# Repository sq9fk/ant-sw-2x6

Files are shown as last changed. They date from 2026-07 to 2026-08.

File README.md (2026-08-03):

# SP9PDF RemoteQTH Antenna Switch (6×2)

Firmware sterownika przełącznika antenowego **6 anten × 2 TRX** oparty na projekcie
[RemoteQTH 6×2 Antenna Controller](https://remoteqth.com/6x2-antenna-controler.php)
(oryginał **OK1HRA**, rev 0.3), zmodyfikowany przez **SQ9FK** na potrzeby stacji **SP9PDF**.

Urządzenie pozwala dwóm transceiverom niezależnie i bezkolizyjnie korzystać ze wspólnego
zestawu anten, z ochroną przed konfliktem, gdy oba TRX żądają tej samej anteny. Sterowanie
odbywa się ręcznie (enkoder/LCD + interfejs WWW); automatyka BCD z radia oraz blokowanie
przez PTT to funkcje **opcjonalne** (patrz [Funkcje opcjonalne](#funkcje-opcjonalne-sq9fk)),
domyślnie wyłączone.

Rozwój firmware (modyfikacje SQ9FK, dokumentacja, symulator WWW) prowadzony jest przy wsparciu
[Claude Code](https://claude.com/claude-code) (Anthropic).

## Sprzęt

- Platforma: **Arduino Nano** (ATmega328P)
- Ekspandery I/O: **MCP23017** na magistrali I²C (adresy 0x20–0x23)
- Wyświetlacz: **LCD 16×2** (jedna linia na TRX)
- Wejścia: enkoder obrotowy + podświetlany przycisk (menu ręczne)
- Pomiar napięcia zasilania na `A3` (ostrzeżenia LOW/HIGH < 10 V / > 15 V)
- Moduł Ethernet **W5500** (interfejs WWW) — w firmware **domyślnie włączony** (`#define EthModule`)

Dokumentacja sprzętowa w repo:
- Schemat (SVG): [`docs/6x2-antenna-switch-control-03-sch.svg`](docs/6x2-antenna-switch-control-03-sch.svg)
- Projekt **KiCad** rev 03 (schemat + PCB + netlista): [`hw/`](hw/)
- **Analiza połączeń** (pinout MCU, I²C, przekaźniki, BCD/PTT, OTRSP), zweryfikowana
  netlistą: [`docs/CONNECTIONS.md`](docs/CONNECTIONS.md)
- **Architektura firmware** (model stanu, pętla, serwer WWW, flagi funkcji):
  [`docs/DESIGN.md`](docs/DESIGN.md)

Źródło sprzętu: RemoteQTH / OK1HRA, licencja **CC BY-SA 4.0**
(<https://remoteqth.com/6x2-antenna-controler.php>).

## Funkcje / modyfikacje SQ9FK

W stosunku do oryginału OK1HRA (rev 0.3) wprowadzono:

- **6 anten (projekt pierwotny)** — czysty one-hot `bit0..bit5` = anteny 1..6 (bez dawnej
  7. pozycji i bez sprzężenia GXP11 4/5).
- **Radio Flex — dwa niezależne wyjścia** na `GPA7`/`GPB7` (przekaźniki `K1`/`K2`, złącza
  `J7`/`J6`), przełączane **ikonami power w wierszach TRX** (WWW), niezależne od wyboru anteny.
  Dawniej `bit7` = przekaźnik pasma GXP11 40 m.
- **Nowy wygląd WWW** wg konwencji projektu
  [`rotator_wifi_bridge`](https://github.com/sq9fk/rotator_wifi_bridge) — ciemny motyw teal, karty,
  statusy sekcji przy nagłówku „Anteny", legenda „Opis anten", zwijana karta **Settings**.
  **Responsywny (mobile-first)** — cele dotykowe min. 44×44 px poniżej 520 px, wyśrodkowana ikona
  Flex, siatka przycisków TRX zawsze wyrównana do lewej krawędzi karty niezależnie od liczby
  zawiniętych linii (etykieta TRX na własnym pełnym wierszu na wąskich ekranach). **Siatka anten
  na mobile (2026-08-02)** — wiersz zawija się deterministycznie na **4+4** (`-,1,2,3` / `4,5,6,
  power`), oba wiersze wypełniają całą szerokość karty równymi przyciskami (`flex:1 1 0`); ikona
  power już nie „ucieka" auto-marginesem na prawy kraniec, gdy zostanie sama w krótkim,
  zawiniętym wierszu (na desktopie bez zmian — nadal przy prawej krawędzi w jednym wierszu).
- **Edycja nazw przez WWW** (`WWW_EEPROM_NAMES`, karta Settings) — **nazwa stacji** (topbar) oraz
  nazwy anten 1–6, zapisywane w EEPROM (trwałe), z limitem długości 11 znaków.
- **Konfiguracja sieciowa edytowalna przez WWW** (karta Settings) — **IP, brama, maska, DNS**
  zamiast na sztywno w kodzie; zapisywane w EEPROM (`IPAddress::fromString`, walidacja — błędny
  adres jest ignorowany, stara wartość zostaje). Zmiana wymaga restartu urządzenia.
- **Awaryjna edycja sieci przez Serial (2026-08-02)** — gdy urządzenie ma źle skonfigurowane IP
  (lub bramę/maskę) i strona WWW jest nieosiągalna, IP/gateway/maska/DNS da się poprawić bez
  sieci: podłącz USB, otwórz terminal szeregowy (9600 8N1, zakończenie linii CR — w Arduino
  Serial Monitor „Both NL & CR" albo „Carriage return") i wyślij `NI=192.168.2.150`
  (analogicznie `NG=`/`NM=`/`ND=` dla bramy/maski/DNS — dokładnie ten sam format co WWW
  `/?N{I|G|M|D}={a.b.c.d}`, tylko bez `/?`). Urządzenie odpowiada `OK` albo `ERR` (błędny adres —
  stara wartość zostaje). Dostępne we wszystkich wariantach ze skonfigurowaną siecią
  (`EthModule` i/lub `OTRSP_TCP`), niezależnie od tego, czy `OTRSP` (USB) jest włączony — jeśli
  jest, komenda `N{kod}=` jest rozpoznawana przed przekazaniem reszty do parsera OTRSP, więc oba
  mechanizmy współdzielą ten sam port bez kolizji.
- **Odczyt stanu dla `rotator_wifi_bridge`** (`GET /?J` → `A=<trx1>,<trx2>`, `GET /?K` →
  `K=<nazwa1>,…,<nazwa6>,<nazwa stacji>`) — pozwala mostowi
  [`rotator_wifi_bridge`](https://github.com/sq9fk/rotator_wifi_bridge) (panel WWW rotora anteny)
  pokazać stan, **prawdziwe nazwy anten**, **nazwę samego przełącznika** i przełączać TRX1/TRX2
  z jednego miejsca, zwykłym HTTP GET (`/?S{bank}{kod}`, tak jak własny panel WWW tego urządzenia)
  — bez OTRSP, które zostaje zarezerwowane wyłącznie dla programu logującego. Oba endpointy
  reużywają istniejący nagłówek HTTP (`HTTP_HEAD`) zamiast nowego literału, koszt: **+68 B** (`/?J`),
  **+72 B** (`/?K`, 6 nazw anten) i dodatkowe **+16 B** za 7. pole (nazwa stacji) zamiast osobnego
  endpointu (patrz `docs/DESIGN.md` §7/§9) — **zapas na domyślnym wariancie to już tylko ~90 B**.
- **Sterowanie OTRSP** (SO2R, zgodne z [protokołem OTRSP](https://www.k1xm.org/OTRSP/OTRSP_Protocol.pdf))
  — komendy `AUX1`/`AUX2`, zapytania `?AUX1`/`?AUX2`/`?NAME`/`?`, zgodne m.in. z N1MM+. Komendy
  kończy CR (`\r`), zgodnie ze specyfikacją. Kanał USB (`OTRSP`, domyślnie **wyłączony**) i surowe
  gniazdo TCP (`OTRSP_TCP`, domyślny port 4534, domyślnie **włączone**) są **niezależne** — można
  włączyć jeden, drugi, albo oba naraz; sam parser komend jest wspólny
  (`OTRSP_parse(cmd, Print&)`), każdy kanał ma własny, niezależny bufor linii. Każdy z nich, oraz
  **oba naraz**, mieszczą się razem ze stroną WWW (`EthModule`) — `OTRSP` (USB) z zapasem ~1,1 KB,
  `OTRSP_TCP` (gniazdo TCP, **domyślny build**) z zapasem ~398 B, oba naraz z zapasem ~346 B
  (patrz uwaga niżej) — żadna kombinacja nie jest już blokowana.
- **Automatyka BCD i blokowanie przez PTT** — dostępne jako opcje (`BCD_INPUT`, `PTT_BLOCKING`),
  domyślnie wyłączone (patrz [Funkcje opcjonalne](#funkcje-opcjonalne-sq9fk)).
- **Watchdog** (`<avr/wdt.h>`, zawsze włączony) — jeśli `loop()` się zawiesi (na WWW, TCP OTRSP,
  USB OTRSP albo czymkolwiek innym) i nie wróci w ciągu ~8 s, urządzenie samo się resetuje.
  Włączany dopiero na końcu `setup()` (po wszystkich `delay()` przy starcie — LCD/IP splash), żeby
  nie zresetować urządzenia w trakcie rozruchu.
- **Przycisk „Restart" w Settings** — realny, programowy restart urządzenia z poziomu WWW (nie
  tylko informacja, że trzeba go ręcznie zrestartować). Wykorzystuje watchdog ze skróconym
  timeoutem (15 ms) — jedyny niezawodny sposób softwarowego resetu na AVR (czyści też peryferia,
  nie tylko licznik rozkazów, w przeciwieństwie do skoku na adres 0).
- **Ostrzeżenia napięciowe** — czerwona kropka statusu w topbarze przy napięciu poza 10–15 V oraz
  ostrzeżenie na LCD — **nieblokujące** (nie zamrażają WWW/przełączania podczas awarii). Samo
  napięcie nie jest już pokazywane liczbowo w Settings (usunięte dla oszczędności flash).
- **Zawsze static IP** — bez DHCP (usunięte z projektu, patrz niżej) — urządzenie startuje pod
  stałym adresem, ustawionym w `src/main.ino` lub edytowalnym po flashowaniu przez WWW+EEPROM
  (patrz „Konfiguracja sieciowa" wyżej), IP na LCD widoczne od razu przy starcie.
- Optymalizacja rozmiaru firmware (PROGMEM, pętle WWW) i utwardzenie serwera WWW.
- **Przegląd bezpieczeństwa/poprawności (2026-07-29)** — 6 poprawek: (1) walidacja zakresu w
  OTRSP `AUX1n`/`AUX2n` (wartości >6 wcześniej powodowały odczyt poza tablicą `antRAM[]` przy
  najbliższym odświeżeniu LCD/WWW); (2) timeout 2 s na odczyt żądania WWW (wolny/zawieszony
  klient trzymał `loop()` w nieskończonej pętli, docelowo do resetu przez watchdog); (3) `volatile`
  dla zmiennych dzielonych z ISR enkodera (`enc0Pos`, `e`, `Timeout[]`); (4) usunięcie `String` z
  `show()` (heap-alokacje co ~100 ms — przy okazji odzyskało **~660 B flash**, znacznie
  poprawiając zapas domyślnego buildu); (5) `enc2()` używa własnego parametru zamiast globalnej
  zmiennej; (6) powiększony bufor żądania WWW (56 B zamiast 48 B — mocno zakodowana 11-znakowa
  nazwa anteny mogła się wcześniej obcinać w połowie).
- **Odblokowany 6. wariant (2026-08-01)** — strona WWW + OTRSP po USB **i** po TCP jednocześnie
  (`EthModule`+`OTRSP`+`OTRSP_TCP`) była dotąd blokowana przez `#error` (brakowało ~116 B); po
  odzyskaniu flash w przeglądzie z 2026-07-29 kombinacja faktycznie się mieści (zmierzone wtedy:
  97,3%/29896 B) — `#error` usunięty, wszystkie sześć wariantów jest teraz dostępnych.
- **Nazwa stacji na LCD wyśrodkowana (2026-08-02)** — była drukowana zawsze od kolumny 0 (z boku
  dla krótszych nazw); teraz liczona jest jej długość (`siteNameLen()`) i wyliczana kolumna
  startowa dla wyśrodkowania na 16-znakowej linii.
- **Strona WWW nie zwija już Settings w trakcie edycji (2026-08-02)** — dawny
  `<meta http-equiv="refresh">` przeładowywał stronę bezwarunkowo co 10 s, więc rozwinięta karta
  Settings (`<details>`, stan tylko w DOM, nie zapisany po stronie urządzenia) zwijała się z
  powrotem, zanim dało się zapisać zmianę. Zastąpione małym inline `<script>`: strona nadal
  odświeża się co 10 s, ale **tylko gdy żaden `<details>` nie jest rozwinięty** — w przeciwnym
  razie sprawdzenie jest odraczane co 2 s, aż użytkownik zwinie Settings.
- **Biblioteka Ethernet: oficjalna `arduino-libraries/Ethernet`** (była `adafruit/Ethernet2` —
  przestarzała/nieutrzymywana). Kosztuje więcej flash niż Ethernet2 (obsługa W5100/W5200/W5500
  z auto-detekcją chipu w runtime, niewyłączalna `#define`m). **DHCP usunięte z projektu** —
  kosztowało ~3,8 KB flash, a przydatne było tylko w wariantach bez strony WWW; nie warto było
  trzymać całej ścieżki kodu dla tego jednego przypadku. Strona WWW działa zawsze na
  **static IP** (ustaw `ip`/`gateway`/`subnet` w `src/main.ino` pod docelową sieć).

Domyślne nazwy anten są w `antDefault[]`, domyślna nazwa stacji w `siteDefault` (`src/main.ino`).
Przy włączonym `WWW_EEPROM_NAMES` nazwa stacji i nazwy anten 1–6 są **edytowalne przez WWW** (karta
Settings) i zapisywane w EEPROM (patrz niżej).

## Konfiguracja (dyrektywy `#define`)

| Define | Domyślnie | Opis |
|---|---|---|
| `Inputs` | 6 | liczba anten (stała — zmiana nie jest w pełni zaimplementowana) |
| `Ports` | 2 | liczba par IN/OUT i linii LCD (wspiera 2–4) |
| `inputHigh` | **WŁ.** | poziom aktywny wejść (HIGH) |
| `OTRSP` | WYŁ. | włącza sterowanie OTRSP po porcie szeregowym |
| `OTRSP_TCP` | **WŁ.** | surowy TCP dla OTRSP — niezależne od `OTRSP`; domyślnie razem z `EthModule` (zapas ~398 B) |
| `OTRSP_TCP_PORT`| 4534 | port surowego TCP dla OTRSP |
| `SERBAUD` | 9600 | prędkość portu szeregowego |
| `EthModule` | **WŁ.** | włącza moduł Ethernet + interfejs WWW (zawsze static IP, bez DHCP) |

### Funkcje opcjonalne (SQ9FK)

| Define | Domyślnie | Opis |
|---|---|---|
| `WWW_EEPROM_NAMES` | **WŁ.** | edycja nazwy stacji i nazw anten 1–6 przez WWW (karta Settings), zapis w EEPROM, limit `ANT_MAXLEN` (11 zn.) |
| `BCD_INPUT` | WYŁ. | automatyczny wybór anteny z BCD radia (wejścia MCP IN); wyłączony = tryb wyłącznie ręczny (WWW/enkoder), bez przełącznika Manual/BCD |
| `PTT_BLOCKING`  | WYŁ. | odczyt PTT + blokada przełączania podczas TX + plakietka PTT; wyłączony zgodnie ze zmianą HW (gniazda PTT jako wyjścia) |

> **Wykrywanie kolizji** między TRX (blokada tej samej anteny, ≠ OFF) działa **niezależnie**
> od `PTT_BLOCKING` — pozostaje aktywne. Blokada pary 4↔5 (GXP11) z projektu OK1HRA została
> usunięta — poz. 4 i 5 to teraz w pełni niezależne anteny.
>
> **Atrybucja kolizji (2026-08-03)** — gdy dwa TRX zażądają tej samej anteny, na czerwono
> podświetla się **tylko ten TRX, który przełączył się jako drugi** (ten pierwszy, już
> ustabilizowany, zostaje bez zmian) — niezależnie od numeru TRX. Górny chip statusu (mały
> kwadrat z numerem TRX) pokazuje wtedy **„OFF"** zamiast nazwy żądanej anteny, bo dokładnie tak
> wygląda stan przekaźników (wyjście zostaje wymuszone na OFF). Żądanie zablokowanego TRX
> **nie ginie** — jeśli TRX, który zajmuje antenę, ją zwolni (przełączy się gdzie indziej albo na
> OFF), zablokowany TRX automatycznie ją przejmuje **od razu, bez ponownego klikania i bez
> odświeżania strony** (poprawka z 2026-08-04 — poprzednio przejęcie działało tylko wtedy, gdy
> zwalniający TRX miał niższy numer niż zablokowany; w drugą stronę zablokowany TRX zostawał
> zawieszony na OFF aż do ręcznego odświeżenia, mimo że antena była już fizycznie wolna).
> Naprawiono też sytuację, w której strona WWW pokazywała kolor kolizji **sprzed** dopiero co
> wykonanej zmiany (trzeba było ręcznie odświeżyć) oraz fałszywe kolizje przy **OFF+OFF**
> (dwa TRX ustawione na OFF nigdy nie kolidują).

## Struktura repozytorium

```
.
├── platformio.ini                 # konfiguracja budowania (Nano / ATmega328P)
├── src/
│   └── main.ino                   # AKTUALNY firmware SP9PDF/SQ9FK
├── reference/                     # firmware referencyjny (nie budowany)
│   ├── ant-sw-6x2-03_orig.ino     #   oryginał OK1HRA rev 0.3
│   ├── ant-sw-6x2-03.ino          #   wariant rev 03
│   └── ant-sw-6x2-04.ino          #   wariant rev 04
├── docs/
│   ├── 6x2-antenna-switch-control-03-sch.svg   # schemat (RemoteQTH rev 03)
│   ├── CONNECTIONS.md             # analiza połączeń (kod + netlista)
│   └── DESIGN.md                  # architektura firmware (model stanu, WWW, flagi)
├── hw/                            # projekt KiCad rev 03 (OK1HRA, CC BY-SA 4.0)
│   ├── 6x2-antenna-switch-control-03.zip
│   └── 6x2-antenna-switch-control-03/   # .sch, .kicad_pcb, .net, .lib, .pro
├── tools/
│   ├── websim.html                # symulator interfejsu WWW (test wyglądu bez sprzętu)
│   └── serve.py                   # launcher: wystawia symulator i otwiera przeglądarkę
├── README.md
├── CLAUDE.md                      # wskazówki dla Claude Code
└── LICENSE                        # GPLv3
```

## Kompilacja i wgranie

### PlatformIO (zalecane)

```bash
# Nano ze STARYM bootloaderem (57600):
pio run -e nanoatmega328 -t upload
# Nano z NOWYM bootloaderem (115200):
pio run -e nanoatmega328new -t upload
# Podgląd portu szeregowego (9600):
pio device monitor -b 9600
```

`Wire`/`SPI` są w rdzeniu AVR; `LiquidCrystal` i `Ethernet` PlatformIO pobiera automatycznie
z `lib_deps` w [`platformio.ini`](platformio.ini). Ethernet (`#define EthModule`/`OTRSP_TCP`
w `src/main.ino`) to oficjalna biblioteka Arduino `arduino-libraries/Ethernet` (2026-07-29:
zastąpiła przestarzałą `adafruit/Ethernet2`).

> **Domyślna konfiguracja: Ethernet WŁ. + OTRSP po TCP WŁ.** (strona WWW + gniazdo TCP dla
> OTRSP, np. dla N1MM+, port 4534 — static IP). Build zweryfikowany: `pio run -e nanoatmega328`
> → **SUCCESS**, bez ostrzeżeń (Flash **98,7%** / 30322 B — **zapas ~398 B**, RAM **55,0%** / 1127 B
> — domyślne flagi: BCD/PTT wył., nazwy WWW wł., konfiguracja sieciowa edytowalna wł. (WWW **i**
> Serial, patrz „Awaryjna edycja sieci przez Serial" wyżej), watchdog wł., endpointy `/?J`+`/?K`
> dla `rotator_wifi_bridge` wł.). Zapas znacząco się poprawił po usunięciu `String` z `show()`
> (patrz niżej) — wcześniej było ~246 B; od tego czasu zjadły go poprawki UX (siatka mobile,
> atrybucja kolizji — patrz wyżej).
> Wariant **BCD+PTT razem z Ethernetem już się nie mieści** — te opcje bez `EthModule`.
>
> ⚠️ **Oficjalna biblioteka Ethernet kosztuje więcej flash niż Ethernet2** (obsługa
> W5100/W5200/W5500 z auto-detekcją chipu w runtime — niewyłączalna `#define`m, zawsze
> skompilowana). **DHCP usunięte z projektu** — kosztowało ~3,8 KB (`Dhcp.cpp`+`EthernetUdp.cpp`),
> przydatne było tylko w wariantach bez strony WWW; urządzenie zawsze startuje na **static IP**
> (ustaw `ip`/`gateway`/`subnet` w `src/main.ino` pod docelową sieć, albo edytuj po flashowaniu
> przez WWW+EEPROM). Sama strona WWW (HTML/CSS/`BufP`) kosztuje dodatkowo ~8 KB — to ona, nie
> sam Ethernet, zajmuje większość budżetu.
>
> `OTRSP` (USB) i `OTRSP_TCP` (gniazdo TCP) są **niezależne** — każdy może być włączony osobno,
> razem albo osobno, ze stroną WWW (`EthModule`) albo bez niej. Od 2026-07-29 (po przeglądzie
> bugów i odzyskaniu ~660 B flash) **żadna kombinacja już nie jest blokowana** — dawny `#error`
> dla `EthModule`+`OTRSP`+`OTRSP_TCP` naraz (brakowało ~116 B) został usunięty, bo ta kombinacja
> faktycznie się mieści. Sześć wariantów (figury poniżej z 2026-08-03, po poprawkach siatki
> mobile i atrybucji kolizji — patrz wyżej):
> - **Strona WWW + OTRSP po surowym TCP** (**obecnie, domyślne**): `#define EthModule`,
>   `//#define OTRSP`, `#define OTRSP_TCP` → Flash **98,7%** (30322 B), RAM **55,0%** (1127 B)
>   — zapas ~398 B. Wciąż najciaśniejszy z domyślnie używanych wariantów — buduj go najpierw przy
>   każdej zmianie we współdzielonym kodzie (patrz `docs/DESIGN.md` §9/§11).
> - **Strona WWW, static IP, bez OTRSP**: `#define EthModule`, `//#define OTRSP`,
>   `//#define OTRSP_TCP` → Flash **95,7%** (29394 B), RAM **50,8%** (1041 B) — zapas ~1,3 KB,
>   bezpieczniejszy wybór jeśli OTRSP nie jest potrzebne.
> - **Strona WWW + OTRSP po USB**: `#define EthModule`, `#define OTRSP`, `//#define OTRSP_TCP`
>   → Flash **97,1%** (29822 B), RAM **50,8%** (1041 B) — zapas ~898 B
> - **Strona WWW + OTRSP po USB i po TCP jednocześnie**: `#define EthModule`, `#define OTRSP`,
>   `#define OTRSP_TCP` → Flash **98,9%** (30374 B), RAM **55,0%** (1127 B) — zapas ~346 B,
>   **najciaśniejszy ze wszystkich sześciu wariantów** (odblokowany 2026-08-01); jeśli oba kanały
>   OTRSP naraz nie są naprawdę potrzebne, wybierz jeden z dwóch wariantów wyżej — mają wyraźnie
>   więcej zapasu.
> - **OTRSP po USB** (bez strony WWW): `//#define EthModule`, `#define OTRSP`, `//#define OTRSP_TCP`
>   → Flash **33,7%** (10340 B), RAM **36,1%** (739 B) — bez konfiguracji sieciowej (brak
>   `EthModule`/`OTRSP_TCP`), więc bez komend `N{I|G|M|D}=` po Serial.
> - **OTRSP po USB + surowy TCP równolegle** (bez strony WWW): `//#define EthModule`,
>   `#define OTRSP`, `#define OTRSP_TCP` → Flash **69,7%** (21412 B), RAM **54,0%** (1106 B)

### Optymalizacje rozmiaru (zastosowane)

- `port[8][6]`, `BCDmatrixOUT` → `byte` / `PROGMEM`; `ant[]` i glify LCD → `PROGMEM`
  (odczyt: `antName()` / `pgm_read_byte` / `memcpy_P`) — **−264 B RAM**.
- Generowanie przycisków WWW (poz. 0–7) i listy anten zwinięte w pętlę, `switch` na `GET`
  uproszczony do `if` — **−1808 B Flash** (bez zmiany wygenerowanego HTML).

### Optymalizacje serwera WWW (zastosowane)

- **Buforowanie całego wyjścia (`BufP`)** — w bibliotekach Wiznet (Ethernet2 i oficjalna
  `arduino-libraries/Ethernet` — sprawdzone w obu) każde `write()` to osobny segment TCP z
  busy-waitem na `SEND_OK`, a `print(F("..."))` wysyła **znak po znaku** (setki drobnych pakietów).
  Klasa `BufP` zbiera znaki w RAM i oddaje do W5500 porcjami 128 B — cała strona idzie w kilkudziesięciu
  `send()` zamiast tysiąca, **wielokrotnie szybciej** i z krótszą blokadą `loop()`. Statyczny HTML
  (nagłówek/CSS/ikona) też przez ten bufor (`out.print`), na końcu `out.done()`.
- **Batchowany odczyt żądania** — dostępne bajty czytane jednym `client.read(buf,len)` (`recv`)
  zamiast po bajcie, koniec linii wykrywany `memchr` — mniej transakcji SPI na wejściu.
- **Walidacja żądania** (kontrola zakresu banku) — obce żądania (`/favicon.ico`, gołe `GET /`)
  nie przełączają już anten i nie piszą poza tablicą `port[]` (usunięty ukryty błąd OOB).
- Czytanie tylko pierwszej linii żądania (`GET …`) + usunięty debug `Serial.print` —
  krótsza obsługa połączenia. Wygenerowany HTML bez zmian.
- Parsowanie żądania **bez `String`** — bank/kod czytane wprost z bufora `char[16]`
  (usunięty globalny `String HTTP_req`). Brak alokacji sterty na ścieżce żądania.

### Arduino IDE

1. Skopiuj `src/main.ino` do katalogu o tej samej nazwie (`main/main.ino`) lub zmień nazwę.
2. Płytka: *Arduino Nano*, procesor *ATmega328P (Old Bootloader)* w razie potrzeby.
3. Wybierz port COM, *Upload*.

> Uwaga: instalacja biblioteki `Ethernet` (Library Manager, oficjalna Arduino) jest wymagana
> dla `EthModule`/`OTRSP_TCP`. Firmware nie używa DHCP (usunięte z projektu) ani nie wymaga
> żadnych patchy biblioteki — urządzenie startuje zawsze na static IP.

## Symulator interfejsu WWW

Podgląd wyglądu strony urządzenia bez sprzętu — odtwarza HTML/CSS generowany przez firmware.
Symuluje też **protokół OTRSP** (`OTRSP_parse()` z `src/main.ino`) — dwie niezależne, włączane
osobno checkboxami sekcje "OTRSP po USB" / "OTRSP po TCP", każda z monitorem terminala
(wysłane na niebiesko, odebrane na zielono — niezależnie od tego, kto w danym trybie jest
"komputerem", a kto "urządzeniem", patrz niżej) i przyciskami szybkich komend
(`?`, `?AUX1`, `?AUX2`, `?NAME`, `AUX101`, `AUX206`). Komendy `AUX1n`/`AUX2n` faktycznie
przełączają antenę na podglądzie WWW — obie symulacje (WWW i OTRSP) dzielą ten sam stan.

```bash
python tools/serve.py
```

Skrypt wystawia stronę lokalnie (domyślnie `http://127.0.0.1:8765/websim.html`) i otwiera ją
w przeglądarce. Można też otworzyć plik [`tools/websim.html`](tools/websim.html) bez serwera —
ale wtedy **nie działają** poniższe dwie funkcje realnego połączenia (wymagają `http://`).

**Prawdziwe połączenia OTRSP** (nie tylko symulacja w JS):
- **USB** — przycisk „Połącz z prawdziwym urządzeniem" w monitorze USB używa
  [Web Serial API](https://developer.mozilla.org/en-US/docs/Web/API/Web_Serial_API)
  (Chrome/Edge) — przeglądarka prosi o wybór **realnego portu COM** i rozmawia bezpośrednio
  z podłączonym przełącznikiem antenowym (9600 8N1, jak `SERBAUD`). Wysyłane komendy i
  odpowiedzi realnego urządzenia widać w tym samym monitorze co w trybie symulacji.
- **TCP** — przycisk „Uruchom most dla N1MM+" otwiera WebSocket do `python tools/serve.py`,
  który jednocześnie nasłuchuje na **prawdziwym porcie TCP 4534** (jak `OTRSP_TCP_PORT`).
  Prawdziwy N1MM+ (albo inny program OTRSP) może się połączyć z `127.0.0.1:4534` dokładnie
  jak z prawdziwym urządzeniem w wariancie `OTRSP_TCP` — komendy trafiają do przeglądarki przez
  most (surowa "rura" bajtów w Pythonie, `tools/serve.py`), a `OTRSP_parse()` w JS liczy
  odpowiedź i odsyła ją z powrotem tym samym mostem. W tym trybie to **symulator gra rolę
  urządzenia** (odwrotnie niż USB, gdzie to my jesteśmy "komputerem" mówiącym do sprzętu).

## Licencja

- **Firmware** (`src/`, `reference/`): **GPL v3** — patrz [`LICENSE`](LICENSE).
  Oryginał © OK1HRA, modyfikacje © SQ9FK.
- **Sprzęt** (`hw/`, schemat): **CC BY-SA 4.0** © OK1HRA / RemoteQTH.com.

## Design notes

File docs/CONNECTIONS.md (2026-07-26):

# Analiza połączeń — SP9PDF RemoteQTH 6×2 Antenna Switch

> **Dwa niezależne źródła, w pełni zgodne:**
> 1. Firmware [`src/main.ino`](../src/main.ino) — pinout MCU i logika I²C.
> 2. Projekt KiCad rev 03 ([`hw/`](../hw/), © OK1HRA, CC BY-SA 4.0) — netlista
>    `ant-sw-control.net` (128 komponentów, 149 sieci), z której wyprowadzono stronę
>    sprzętową. Pozycje oznaczone **✓ netlista** są potwierdzone bezpośrednio połączeniami PCB.

Płyta rev 03 to wersja **2-portowa (6 anten × 2 TRX)**: 1× Arduino Nano, 2× MCP23017,
2× ULN/UDN (drivery), opcjonalny W5500 (Ethernet), LM2576 (zasilanie).

> **⚠️ Sprzęt vs firmware.** Ten dokument opisuje **możliwości sprzętu** (płyta OK1HRA rev 03).
> Domyślna konfiguracja firmware SQ9FK **nie używa** części z nich:
> - **Ethernet WŁ.** (interfejs WWW), **OTRSP WYŁ.** (wyklucza się rozmiarowo z Ethernetem);
> - wejścia **BCD** (`BCD_INPUT`) i **odczyt/blokada PTT** (`PTT_BLOCKING`) — **wyłączone**;
> - na tej stacji gniazda **PTT przerobiono sprzętowo na wyjścia** (nie służą jako wejścia PTT).
>
> Sekcje 4 (BCD/PTT) i 6 (OTRSP) opisują więc funkcje **opcjonalne**. Wyjścia anten (sekcja 3),
> I²C, LCD, enkoder, zasilanie i wykrywanie kolizji działają zawsze.

## 1. Mikrokontroler — Arduino Nano (ATmega328P) `U8`

Nazwy sieci w schemacie odpowiadają 1:1 definicjom w firmware — **✓ netlista**:

| Pin Nano | Sieć (KiCad) | Funkcja | Firmware |
|---|---|---|---|
| A0  | `/RS` | LCD RS → `U9.4` | `lcd(A0,...)` |
| A1  | `/E` | LCD E → `U9.6` | `lcd(A0,A1,...)` |
| D7  | `/D4` | LCD D4 → `U9.11` | `lcd(...,7,...)` |
| D6  | `/D5` | LCD D5 → `U9.12` | `lcd(...,6,...)` |
| D5  | `/D6` | LCD D6 → `U9.13` | `lcd(...,5,...)` |
| D4  | `/D7` | LCD D7 → `U9.14` | `lcd(...,4)` |
| D2  | `/ENC-A`  | Enkoder A (RC: R5/C2) | `enc0PinA = 2` |
| D3  | `/ENC-B`  | Enkoder B (RC: R8/C6), INT1 | `enc0PinB = 3` |
| D9  | `/SW` | Przycisk `S1` | `sw = 9` |
| D8  | `/SW-LED` | LED przycisku (R36) | `swLED = 8` |
| A3  | `/12V` | Pomiar napięcia (dzielnik R3/R4) | `analogRead(A3)` |
| A4  | `/SDA` | I²C → `U5.13`, `U6.13` (pull-up R26) | `Wire` |
| A5  | `/SCL` | I²C → `U5.12`, `U6.12` (pull-up R25) | `Wire` |
| D0/D1 | `/RX` `/TX` | Serial 9600 — OTRSP/SO2R (opcja, dom. wył.) | `#define OTRSP` |
| D10–D13 | `Net-(U1-*)` | SPI → W5500 (`U1`) — dom. **wł.** | `#define EthModule` |
| 3V3 | `+3V3` | zasilanie W5500 | — |
| A2, A6, A7, AREF | — | niepodłączone | — |

Pomiar napięcia: `volt = analogRead(A3)*5/1024*7.25 + 0.4`. Dzielnik R3/R4 od szyny `/12V`,
ostrzeżenia LCD przy `< 10 V` / `> 15 V` (nominał 13,8 V).

## 2. Ekspandery I²C MCP23017

| Ozn. | Adres | Rola | GPIOA | GPIOB |
|---|---|---|---|---|
| `U5` | `0x20` | **OUT** | TRX1 → ULN `U7` | TRX2 → ULN `U4` |
| `U6` | `0x21` | **IN**  | BCD (P4=TRX1, P3=TRX2) | PTT (`GPB0/GPB1`) |

> Rev 03 ma fizycznie **2 ekspandery** (`0x20`+`0x21`) — to wersja 2-TRX. Adresy `0x22`/`0x23`
> z firmware dotyczą rozbudowy do 4 TRX. Adres ustawiają zworki na A0/A1/A2. Rejestry:
> `IODIRA=0x00`, `IODIRB=0x01`, `GPIOA=0x12`, `GPIOB=0x13`.

## 3. Wyjścia anten — ✓ netlista

`U5` (OUT) steruje wejściami dwóch driverów ULN/UDN, których wyjścia (open-collector, 12 V)
trafiają przez ferryty na gniazda **RJ45**:

| Sygnał logiczny | U5 pin | Driver | Wyjście |
|---|---|---|---|
| TRX1 anteny 1–6 | `GPA0..GPA5` | `U7` (ULN) | **RJ45 `J2`** (przez L29/L31/L35/L39/L43/L47) |
| TRX2 anteny 1–6 | `GPB0..GPB5` | `U4` (ULN) | **RJ45 `J1`** (przez L5/L7/L11/L15/L19/L23) |
| **Radio Flex 1** | `GPA7` → R2 → `Q1` | przekaźnik `K1` | styki na **`J7`** |
| **Radio Flex 2** | `GPB7` → R1 → `Q2` | przekaźnik `K2` | styki na **`J6`** |
| (nieużywane) | `GPA6`, `GPB6` | — | — (firmware `bit6` wolny) |

Kodowanie one-hot z funkcji `tx()` (numer anteny → bit portu) — **projekt 6-antenowy**:

| Poz. | Antena | Bit | Uwaga |
|---|---|-----|---|
| 1 | 160m INV-V | `bit0` | |
| 2 | 80m Dipole | `bit1` | |
| 3 | Delta 80/40  | `bit2` | |
| 4 | (nazwa WWW)  | `bit3` | niezależna antena |
| 5 | (nazwa WWW)  | `bit4` | niezależna antena |
| 6 | UB50 | `bit5` | |
| 0 | OFF | `0x00` | |

> **SQ9FK (zmiana):** `bit7` (GPA7/GPB7) **nie należy już do anteny** — steruje dwoma
> **niezależnymi wyjściami Radio Flex** (`flexState[]`), przełączanymi osobnymi przyciskami WWW,
> niezależnie od wyboru anteny. Dawniej `bit7` = przekaźnik pasma GXP11 40 m sprzężony z poz. 4/5.
> Poz. 4 i 5 to teraz **niezależne anteny** (`bit3`/`bit4`), więc blokada kolizji 4↔5 została
> usunięta — pozostaje ogólne wykrywanie kolizji (ta sama antena na obu TRX).

## 4. Wejścia BCD + PTT — ✓ netlista

> **Funkcja opcjonalna — domyślnie nieaktywna.** Poniższa ścieżka wejściowa jest obsługiwana
> przez firmware tylko przy `#define BCD_INPUT` (odczyt BCD) i `#define PTT_BLOCKING` (PTT) —
> oba domyślnie **wyłączone**. `U6` (IN) nie jest wtedy czytany (`rx()` nie jest kompilowany),
> a `port[i][1]` ustawia się wyłącznie ręcznie (WWW/enkoder). Na tej stacji gniazda PTT są
> ponadto przerobione na **wyjścia** (zmiana HW poza tą netlistą).

Dane pasma z radia wchodzą na złącza **P3/P4** (ferryt + R9–R16 + RC), do `U6` (IN):

| Złącze | Piny | → U6 | Rola |
|---|---|---|---|
| **`P4`** | 2–5 | `GPA0..GPA3` (dolny nibble) | **TRX1** BCD → `BCDmatrixOUT[0][]` |
| **`P3`** | 2–5 | `GPA4..GPA7` (górny nibble) | **TRX2** BCD → `BCDmatrixOUT[1][]` |
| `P3/P4` | 6 | `+5V` (L57) | zasilanie |
| — | `GPB1` (D3/R34) | PTT **TRX1** | blokada podczas TX |
| — | `GPB0` (D4/R35) | PTT **TRX2** | blokada podczas TX |

Poziom aktywny wejść: **HIGH** (`#define inputHigh`). `GPB2..GPB7` na masie (nieużywane).
Tablica `BCDmatrixOUT[2][16]` mapuje 16 kodów pasma → numer anteny:
```
{ 0, 1, 2, 3, 4, 5, 4, 5, 4, 5, 6, 3, 3, 3, 3, 3 }
```

## 5. Złącza i zasilanie — ✓ netlista

| Ozn. | Typ | Funkcja |
|---|-----|---|
| `J5` | DC jack | wejście zasilania ~12 V (→ LM2576 `U10` → +5 V; warystor V1, bezp. F1) |
| `J1` | RJ45 | wyjście sterowania anten **TRX2** (6 linii + `+12V` pin8 + GND) |
| `J2` | RJ45 | wyjście sterowania anten **TRX1** (6 linii + `+12V` pin8 + GND) |
| `P4` | header | wejście BCD **TRX1** (4 bity + 5 V + GND) |
| `P3` | header | wejście BCD **TRX2** (4 bity + 5 V + GND) |
| `J7` | 2-pin | styki przekaźnika `K1` — pasmo GXP11 **TRX1** |
| `J6` | 2-pin | styki przekaźnika `K2` — pasmo GXP11 **TRX2** |
| `P1`, `P2` | header | rozbudowa I²C (SDA/SCL/5V/GND) — kolejne porty |
| `J1/J2` `U1` | RJ45 / moduł | opcjonalny Ethernet W5500 (SPI, `#define EthModule`) |

## 6. Sterowanie z komputera — OTRSP (SO2R)

> **Funkcja opcjonalna — domyślnie nieaktywna** (`#define OTRSP`). Wyklucza się rozmiarowo
> z Ethernetem (30 KB flash), więc w domyślnym buildzie z WWW jest wyłączona.

Port szeregowy Nano (D0/D1, 9600 8N1), obsługa w `OTRSP_parse()`:

| Komenda | Działanie |
|---|---|
| `AUX1n` / `AUX2n` | ustaw antenę TRX1 / TRX2 (4-bit) |
| `?AUX1` / `?AUX2` | odczyt bieżącej wartości |
| `?NAME` | zwraca `2x6SP9PDFRemoteAntennaSwitch` |
| `?` | ping |

## 7. Schemat blokowy

```
                 P4 (BCD TRX1) ┐         ┌ RJ45 J2 → anteny TRX1 (open-coll. 12V)
                 P3 (BCD TRX2) ┤         │ RJ45 J1 → anteny TRX2
                    PTT ────────┤         │
                                ▼         │
   Radio ─BCD─►  [ U6 MCP23017 0x21 IN ]  │        LCD U9 ◄─ A0,A1,D4-D7
                          ▲ I²C (A4/A5)   │        Enkoder ◄─ D2,D3 + S1(D9),LED(D8)
                    [ Arduino Nano U8 ]───┼──I²C── Uzas.  ◄─ A3 (/12V, dziel. R3/R4)
                          │ I²C           │        PC/SO2R◄─ D0/D1 (OTRSP)
                          ▼               │        W5500  ◄─ D10-D13 (opcja)
                 [ U5 MCP23017 0x20 OUT ]─┘
                    │GPA→U7(ULN)  │GPB→U4(ULN) │GPA7/GPB7→Q1/Q2→K1/K2
                    └─ anteny 1-6 ┘            └─ przekaźniki pasma GXP (J7/J6)

   Zasilanie: J5 (DC) → V1/F1 → LM2576 (U10) → +5V ; +12V rozprowadzane na RJ45/BCD
```

## 8. Zestawienie kluczowych układów (BoM — wybór)

| Ozn. | Wartość | Rola |
|---|---|---|
| `U8` | Arduino Nano 3.0 | mikrokontroler |
| `U5`, `U6` | MCP23017 | ekspandery I²C (OUT / IN) |
| `U4`, `U7` | ULN/UDN | drivery open-collector do RJ45 |
| `U9` | HD44780 16×2 | wyświetlacz LCD |
| `U1` | W5500 (USR-ES1) | Ethernet (opcja) |
| `U10` | LM2576 | przetwornica step-down +5 V |
| `K1`, `K2` | przekaźnik | pasmo GXP11 (40 m / 20-10 m) |
| `Q1`, `Q2` | tranzystor | sterowanie cewek K1/K2 |
| `V1` / `F1` | warystor 18 V / bezpiecznik | ochrona wejścia zasilania |
| `S1` | mikroprzełącznik | przycisk enkodera |

*Pełna netlista i komponenty: [`hw/6x2-antenna-switch-control-03/ant-sw-control.net`](../hw/6x2-antenna-switch-control-03/ant-sw-control.net).*

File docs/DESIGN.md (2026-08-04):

# DESIGN — architektura firmware SP9PDF RemoteQTH 6×2 Antenna Switch

Opis budowy i działania firmware [`src/main.ino`](../src/main.ino). Sprzęt i pinout:
[`CONNECTIONS.md`](CONNECTIONS.md). Bazuje na RemoteQTH 6×2 (OK1HRA rev 0.3), zmodyfikowany
przez SQ9FK dla stacji SP9PDF.

## 1. Przegląd

Sterownik pozwala **2 transceiverom** dzielić **6 anten** bezkolizyjnie. Antenę dla każdego
TRX wybiera się:
- **ręcznie** — interfejs WWW (Ethernet) lub enkoder + LCD (zawsze dostępne);
- **automatycznie** — z danych pasma BCD radia (opcja `BCD_INPUT`, domyślnie wył.);
- **z komputera** — OTRSP/SO2R, po USB (opcja `OTRSP`, domyślnie wył.) lub po TCP (opcja
  `OTRSP_TCP`, **domyślnie wł.** razem ze stroną WWW, np. do N1MM+).

Rdzeń logiki (wybór anteny → wyjścia przekaźników, wykrywanie kolizji, LCD) działa niezależnie
od opcji. Pętla `loop()` jest jednowątkowa i nieblokująca poza obsługą pojedynczego żądania WWW.

## 2. Konfiguracja i flagi funkcji

Wszystkie `#define` są na górze `src/main.ino`.

| Flaga | Dom. | Znaczenie |
|---|---|---|
| `Ports` | 2 | liczba TRX / linii LCD (2–4) |
| `Inputs` | 6 | liczba anten (etykieta „6x2") |
| `EthModule` | **wł.** | Ethernet W5500 + serwer WWW (zawsze static IP, bez DHCP) |
| `WWW_EEPROM_NAMES` | **wł.** | edycja nazw anten przez WWW + zapis EEPROM |
| `ANT_MAXLEN` | 11 | limit długości nazwy anteny (szerokość LCD) |
| `BCD_INPUT` | wył. | automatyczny wybór anteny z BCD radia (`rx()`) |
| `PTT_BLOCKING` | wył. | odczyt PTT + blokada przełączania podczas TX |
| `OTRSP` | wył. | sterowanie SO2R po porcie szeregowym (USB) |
| `OTRSP_TCP` | **wł.** | surowe gniazdo TCP dla OTRSP — niezależne od `OTRSP`; domyślnie razem z `EthModule` (zapas ~398 B) |
| `OTRSP_TCP_PORT` | 4534 | port surowego TCP dla OTRSP |
| `inputHigh` | wł. | poziom aktywny wejść BCD |

**Ograniczenie rozmiaru:** ATmega328 ma 30 KB flash / 2 KB RAM. `OTRSP` i `OTRSP_TCP` są
**niezależne od siebie** — wspólny `OTRSP_parse()` kompiluje się, gdy zdefiniowany jest
którykolwiek z nich (patrz §8). `EthModule` (strona WWW) **mieści się z każdym z nich osobno,
oraz z oboma naraz**: samo `OTRSP` (USB) — zmierzone **97,1%**, zapas ~898 B; samo `OTRSP_TCP`
(gniazdo TCP) — zmierzone **98,7%**, zapas **~398 B**; **oba naraz**
(`EthModule`+`OTRSP`+`OTRSP_TCP`) — zmierzone **98,9%**, zapas ~346 B, **najciaśniejszy ze
wszystkich sześciu wariantów** (patrz §9). Do 2026-07-30 ta ostatnia kombinacja była zablokowana
przez `#error` w compile-time (brakowało ~116 B); po przeglądzie bugów 2026-07-29 (odzyskane
~660 B z usunięcia `String`) kombinacja faktycznie się mieściła, a **2026-08-01 `#error` został
usunięty** — wszystkie sześć wariantów jest teraz dostępnych. **Domyślnie: Ethernet wł. +
`OTRSP_TCP` wł.** (strona WWW + OTRSP po TCP), `OTRSP` (USB) wył. — to drugi najciaśniejszy
z sześciu wariantów i jest teraz domyślny, patrz §9/§11.
**Sześć wariantów** — patrz §9, §11.

## 3. Model stanu — `port[8][6]`

Centralna tablica stanu (`byte`):

```
port[0..3] = wejścia TRX1..4   (żądana antena)
port[4..7] = wyjścia TRX1..4   (antena wystawiona na przekaźniki)
```

Kolumny:

| idx | nazwa | znaczenie |
|-----|---|---|
| `[0]` | adres | adres I²C ekspandera MCP23017 |
| `[1]` | antena | wybrana/żądana antena: `0`=OFF, `1..6`, `7`=tryb BCD (tylko `BCD_INPUT`) |
| `[2]` | PTT | stan PTT (tylko `PTT_BLOCKING`) |
| `[3]` | kolizja | 1 = konflikt z drugim TRX |
| `[4]` | tryb | 0=auto/BCD, 1=ręczny (istotne tylko przy `BCD_INPUT`) |
| `[5]` | bank | 1 lub 2 (który nibble/half ekspandera) |

Adresy: TRX1/2 → IN `0x21` + OUT `0x20`; TRX3/4 → IN `0x23` + OUT `0x22`. W wersji 2-TRX
używane są `0x20`/`0x21`.

## 4. Pętla główna `loop()`

Kolejność w każdej iteracji:

0. **Watchdog + restart** — `wdt_reset()` na samym początku (jeśli `loop()` się zawiesi i nie
   wróci tu w ciągu ~8 s, AVR resetuje się sam — patrz §9 „Watchdog"). *(opcja `EthModule`)*
   jeśli `pendingRestart` (ustawione przez `/?R1` w poprzedniej iteracji, patrz §7) —
   `wdt_enable(WDTO_15MS); while(1){}` — restart urządzenia, **przed** czymkolwiek innym w tej
   iteracji (klient WWW już dostał pełną odpowiedź w poprzedniej iteracji).
1. **(opcja) OTRSP i/lub edycja sieci przez USB** — jeśli przyszła kompletna komenda serial
   (`serialEvent()`, terminator CR): jeśli pasuje do wzorca `N{I|G|M|D}=` (od 2026-08-02, patrz
   §7 „awaryjna edycja sieci") — obsłuż ją i odpowiedz `OK`/`ERR`; w przeciwnym razie *(opcja
   `OTRSP`)* `OTRSP_parse(in_buf, Serial)`.
2. **GPIO / logika przełączania**:
   - *(opcja `BCD_INPUT`)* dla każdego TRX `i`, jeśli tryb auto → `rx()` czyta antenę z BCD radia;
   - `updateCollisions()` (patrz §9 „Kolizje: 4 poprawki") — dla każdego TRX `i`: licznik `c`
     porównuje `port[i][1]` (żądanie) z `port[j+4][1]` (wyjście INNEGO TRX, nie jego żądanie).
     Kolizja gdy ta sama antena (≠0 — jawny warunek `port[i][1] != 0`, od 2026-08-03; wcześniej
     jego brak dawał fałszywe kolizje przy OFF+OFF). (Blokada 4↔5 GXP usunięta — 6 anten.)
     Jeśli kolizja → `port[i][3]=1`, wyjście OFF; inaczej → wyjście = żądanie *(przy
     `PTT_BLOCKING` przełączenie wstrzymane, gdy PTT aktywne)*; `tx()` wystawia wyjścia na
     ekspander OUT. Ta sama funkcja jest wołana **dodatkowo** zaraz po sparsowaniu `/?S{bank}
     {poz}` w kroku 3 (patrz §7) — inaczej odpowiedź WWW renderowałaby kolor kolizji sprzed
     dopiero co wykonanej zmiany.
3. **(opcja `EthModule`)** obsługa jednego klienta strony WWW (patrz §7) + *(opcja `OTRSP_TCP`)*
   obsługa **trwałego** połączenia OTRSP-TCP (patrz §6 — inny model niż request/response WWW).
4. **(opcja `serialECHO`)** — telemetria na serial.
5. **Przycisk** — długie naciśnięcie przełącza `menu1state` (tryb edycji enkoderem).
6. **LCD** — odświeżenie linii (`show()`) co 100 ms + kontrola napięcia co 3 s. Ostrzeżenia
   LOW/HIGH są **nieblokujące** (znacznik `voltWarn`, ~2 s bez `delay()`) — awaria napięcia nie
   zamraża WWW/przełączania/enkodera.

**Start (`setup()`).** Pierwsze linie: `MCUSR=0; wdt_disable();` — niektóre bootloadery nie
czyszczą włączonego watchdoga przed skokiem do aplikacji; bez tego, po resecie WDT z krótkim
timeoutem (np. z przycisku Restart), urządzenie wpadłoby w pętlę resetów. Splash LCD (2 s) +
napięcie (3 s) dają czas na rozruch W5500. **DHCP usunięte z projektu** (koszt ~3,8 KB
z oficjalną biblioteką nie mieścił się razem ze stroną WWW, a poza WWW nie było go sensu
trzymać dla jednego wariantu — patrz §9) — `Ethernet.begin(mac, ip, myDns, gateway, subnet)`
woła się **zawsze bezpośrednio**, bez retry-loop ani fallbacku. **IP pokazywane na LCD (5 s)**
przez `lcd.print(Ethernet.localIP())` — uwzględnia ewentualną edycję `ip`/`gateway`/`subnet`
przez WWW Settings + EEPROM, załadowaną wcześniej przez `loadNetConfig()`. **Watchdog włączany
na samym końcu** `setup()` (`wdt_enable(WDTO_8S)`) — musi być **po** wszystkich `delay()`
powyżej (łącznie do ~10 s w wariancie z `EthModule`/`OTRSP_TCP`), inaczej WDTO_8S (najdłuższy
pojedynczy timeout AVR) zresetowałby urządzenie w trakcie rozruchu, zanim dojdzie do `loop()`.

## 5. Wyjścia anten — `tx()`

Numer anteny kodowany **one-hot** na porcie ekspandera OUT (`GPIOA`=TRX1, `GPIOB`=TRX2) —
**projekt 6-antenowy** (`bit0..bit5` = anteny 1..6):

| Antena | Bit |
|---|-----|
| 1 | `bit0` |
| 2 | `bit1` |
| 3 | `bit2` |
| 4 | `bit3` |
| 5 | `bit4` |
| 6 | `bit5` |
| 0 (OFF) | `0x00` |

**`bit7` = Radio Flex (SQ9FK):** `GPA7`/`GPB7` sterują dwoma **niezależnymi wyjściami Radio Flex**
(`flexState[0]`/`flexState[1]` → Q1/K1/J7 i Q2/K2/J6), nakładanymi na bajt one-hot **niezależnie od
wyboru anteny**. Przełączane **ikonami power w wierszach TRX** (`/?F{s}{0|1}`), bez konfigurowalnych
nazw. Dawniej `bit7` = przekaźnik pasma GXP11 40 m sprzężony z poz. 4/5.
`bit6` nieużywany. Poz. 4 i 5 to teraz niezależne anteny → **blokada kolizji 4↔5 usunięta**
(ogólne wykrywanie kolizji między TRX pozostaje).

## 6. Wybór anteny — źródła

- **Enkoder/LCD:** przerwanie `encI()` + `enc2()`; `menu1state` przełącza między wyborem
  linii a zmianą numeru anteny. Zakres 0..6 (0..7 przy `BCD_INPUT`, gdzie 7 = tryb BCD).
- **WWW:** żądanie `GET /?S{bank}{kod}` (antena), `GET /?F{s}{0|1}` (Radio Flex) (patrz §7).
- **(opcja) BCD:** `rx()` czyta 4-bit BCD z ekspandera IN, dekoduje przez `BCDmatrixOUT[2][16]`
  (PROGMEM) → numer anteny.
- **(opcja) OTRSP:** `AUX1n`/`AUX2n` ustawiają antenę TRX1/TRX2; `?AUX1/?AUX2/?NAME/?` — zapytania.
  Zgodnie ze specyfikacją [OTRSP](https://www.k1xm.org/OTRSP/OTRSP_Protocol.pdf) komendy kończy
  znak **CR (`\r`)** — `serialEvent()` terminuje na `\r` (LF ignorowany, na wypadek CRLF), z
  kontrolą granic `in_buf`. Odpowiedzi `?AUX1`/`?AUX2` zwracają samą wartość dziesiętną (bez
  dopełnień) — zgodny round-trip `AUXn` → `?AUXn`. Parser `OTRSP_parse(char *cmd, Print &out)`
  przyjmuje bufor komendy i cel odpowiedzi (`Print&`) — używany identycznie z USB (`Serial`) i,
  przy `OTRSP_TCP`, z surowego gniazda TCP (`EthernetClient`); zero duplikacji logiki komend.
  **Kompiluje się, gdy zdefiniowany jest `OTRSP` LUB `OTRSP_TCP`** (`#if defined(OTRSP) ||
  defined(OTRSP_TCP)`) — surowy kanał TCP nie ciągnie za sobą `serialEvent()`/`in_buf` (kod
  USB), których nie potrzebuje. Od 2026-08-02 `serialEvent()`/`in_buf` **NIE SĄ** już
  specyficzne wyłącznie dla `OTRSP` — kompilują się też, gdy istnieje konfiguracja sieciowa
  (`WWW_EEPROM_NAMES && (EthModule||OTRSP_TCP)`), bo obsługują TAKŻE awaryjną edycję sieci przez
  Serial (patrz §7), niezależnie od stanu `OTRSP`. `loop()` sprawdza wzorzec `N{IGMD}=` PRZED
  wywołaniem `OTRSP_parse()` na kanale USB — jeśli pasuje, obsługuje go i **nie** woła
  `OTRSP_parse()` (brak kolizji: komendy SET protokołu OTRSP to `AUX1`/`AUX2`, bez litery `N`).
- **(opcja) OTRSP przez TCP (`OTRSP_TCP`, niezależne od `OTRSP`):** dodatkowy `EthernetServer
  otrspServer(OTRSP_TCP_PORT)` (domyślnie port 4534) w `loop()`. **Połączenie trwałe** — inaczej
  niż serwer WWW (accept→jedna linia→odpowiedź→`stop()`), klient `otrspClient` jest trzymany
  między iteracjami `loop()`, dopóki sam się nie rozłączy; komendy mogą przychodzić wieloma
  porcjami w czasie. Własny bufor linii `otrsp_tcp_buf`/`otrsp_tcp_len`, niezależny od USB
  (`in_buf`) — oba kanały działają **równolegle**, bez wzajemnego mieszania komend. Jeden aktywny
  klient TCP na raz (nowe połączenie zastępuje bieżące przy odbiorze danych — rozróżniane po
  numerze gniazda, `EthernetClient::operator==`). Wymaga `EthModule` **wyłączonego** — patrz §2/§9.

## 7. Serwer WWW (przy `EthModule`)

Jednowątkowy serwer HTTP na porcie 80 (biblioteka `arduino-libraries/Ethernet`, oficjalna Arduino,
W5500 — auto-detekcja chipu; do 2026-07-29 była `adafruit/Ethernet2`, przestarzała/nieutrzymywana).

**Odczyt żądania.** Czytana jest **tylko pierwsza linia** (`GET …`) do bufora `reqBuf`
(bez `String`), z twardym limitem długości. Po znaku `\n` serwer od razu generuje odpowiedź
i kończy (`delay(1); client.stop()`).

**Parsowanie** (z `reqBuf`, indeksy liczone od początku linii):
- `S{bank}{kod}` — `bank`=`reqBuf[7]`, `kod`=`reqBuf[8..9]`:
  `00..06`=antena, `20`=tryb BCD, `21`=tryb ręczny. Walidacja cyfr + `bankIdx ∈ 0..Ports-1`
  (obce żądania jak `/favicon.ico` są ignorowane — brak przypadkowych przełączeń).
- `J` — **odczyt stanu dla `rotator_wifi_bridge`** (SQ9FK): odpowiedź
  `A={port[0][1]},{port[1][1]},{flexState[0]},{flexState[1]},{port[0][3]},{port[1][3]}` (antena
  TRX1,TRX2; Radio Flex/"PWR" TRX1,TRX2 — 3./4. pole, dodane 2026-08-03; flaga kolizji TRX1,TRX2
  — 5./6. pole, dodane 2026-08-04, +36 B na wariancie domyślnym, patrz §9), bez pełnej strony.
  Reużywa `HTTP_HEAD` zamiast nowego literału PROGMEM — konsumentem jest parser na moście (szuka
  podciągu `A=`), nie przeglądarka, więc rezygnacja z poprawnego HTML-a nic nie kosztuje, a
  endpoint jest tani we flashu. Bez tego most musiałby parsować pełny HTML karty Anteny, co jest
  kruche przy każdej zmianie jej wyglądu. Flex dodano, żeby most mógł pokazać **prawdziwy** stan
  przycisku PWR per TRX, nie tylko to co ostatnio wysłał. Flaga kolizji (`port[i][3]`, patrz §9
  „Kolizje") dodana, bo most wcześniej liczył kolizję sam, symetrycznie, z samych numerów anten
  (`ant1==ant2`) — pokazywał **oba** TRX na czerwono zamiast tylko tego, który faktycznie
  przegrał (`updateCollisions()` już wylicza to poprawnie, asymetrycznie, tylko nie wysyłał tego
  dalej). Reużywa istniejące pole zamiast nowego endpointu — ten sam wzorzec co Flex.
- `K` — **nazwy anten dla `rotator_wifi_bridge`** (SQ9FK): odpowiedź `K=` + 6 nazw (`antName(k)`,
  k=1..6) rozdzielonych przecinkiem, tak żeby jego legenda pokazywała **prawdziwe** nazwy z tego
  urządzenia zamiast osobnej, ręcznie duplikowanej kopii po drugiej stronie. Ta sama zasada co `J`
  (reużywa `HTTP_HEAD`), ale droższa — pętla po 6 nazwach zmiennej długości zamiast dwóch liczb —
  **+72 B, zapas na domyślnym wariancie spadł do ~106 B** (patrz §9). Separator `,`: nazwa anteny
  nie powinna go zawierać (`parseName()` tego nie zabrania, ale nikt tak nie robi).
- `F{s}{0|1}` — **Radio Flex** (SQ9FK): `s`=`reqBuf[7]` (1/2), stan=`reqBuf[8]` → `flexState[s-1]`.
- `R1` — **Restart** (przycisk w Settings): ustawia `pendingRestart`; sam restart (watchdog
  z timeoutem 15 ms) wykonuje się dopiero na początku **następnej** iteracji `loop()` (patrz §4),
  żeby klient najpierw dostał pełną, normalnie wyrenderowaną odpowiedź.
- *(opcja `WWW_EEPROM_NAMES`)* `N{k}={nazwa}` — `k`=`reqBuf[7]` (1..6); `parseName()` dekoduje
  URL (`+`→spacja, `%XX`) do `antRAM[k]` z obcięciem do `ANT_MAXLEN`, potem `saveAntNames()`.
- *(opcja `WWW_EEPROM_NAMES`)* `NS={nazwa}` — nazwa stacji (topbar) → `siteRAM` (`parseName()` + `saveAntNames()`).
- *(opcja `WWW_EEPROM_NAMES`)* `N{I|G|M|D}={a.b.c.d}` — **konfiguracja sieciowa** (IP/gateway/maska/DNS)
  zamiast na sztywno w kodzie. Wspólna `setNetField(char code, const char* val)` (współdzielona
  też z Serial, patrz niżej) woła `parseIPField()`, która kopiuje wartość do bufora i woła
  `IPAddress::fromString()` (biblioteka Arduino — nie własny parser); parsuje do zmiennej
  tymczasowej, commituje do żywej `ip`/`gateway`/`subnet`/`myDns` tylko gdy poprawny adres
  (błędny input jest **ignorowany**, stara wartość zostaje), potem `saveNetConfig()`. Zmiana
  wymaga restartu urządzenia (IP nie jest przeładowywane w locie).
- **Settings zostaje rozwinięte po zapisie (2026-08-02):** każde pole Settings ma **własny**
  `<form>`/submit (parser czyta tylko jeden parametr na żądanie), więc zapisanie całej
  konfiguracji sieciowej to do 4 kliknięć OK z rzędu — wcześniej strona za każdym razem
  renderowała `<details>` domyślnie zwinięte, trzeba więc było klikać „Settings” ponownie przed
  edycją kolejnego pola. Lokalna flaga `settingsOpen` (ustawiana w każdej gałęzi edycji: nazwa
  anteny/stacji/pole sieciowe) renderuje `<details open>` zamiast zwiniętego, gdy cokolwiek w
  Settings zostało właśnie zapisane. W połączeniu z auto-odświeżaniem z §9 (wstrzymuje się przy
  otwartym `[open]`) można zapisać IP/gateway/maskę/DNS po kolei bez ponownego rozwijania karty.
- **Awaryjna edycja sieci przez Serial (2026-08-02, *(opcja `WWW_EEPROM_NAMES` && (`EthModule`
  || `OTRSP_TCP`))*):** `N{I|G|M|D}={a.b.c.d}\r` po USB — dokładnie ten sam format co WWW, tylko
  bez `/?`, wołający tę samą `setNetField()`; odpowiedź `OK`/`ERR`. Przydatne, gdy sieć jest źle
  skonfigurowana i strony WWW nie da się osiągnąć. Patrz §6 (kolejność w `loop()`) i §9 (koszt
  flash/RAM, poszerzenie guardu `serialEvent()`/`in_buf`).

**Generowanie strony.** **Całość idzie przez bufor wyjścia `BufP out(client)`** (patrz §9) — `out.print`/
`out.println`, na końcu `out.done()`. Statyczny nagłówek HTTP + `<head>` + CSS + ikona `POWER_SVG` są
w **PROGMEM** (`HTTP_HEAD`/`HTTP_HEAD2`/`POWER_SVG`) i lecą przez ten sam bufor. Dynamicznie (w
kontenerze `.wrap`, sekcje `.card`): **topbar** (kropka `.dot`
czerwona przy napięciu poza 10–15 V + nazwa stacji, `.tb`); karta **Anteny** — nagłówek `.ahead`
ze **statusami sekcji** (`.astat`/`.st`, chipy 50/50: numer + nazwa włączonej anteny) oraz wiersze
TRX `.trx` (przyciski anten w pętli, klasy `g`/`gr` = wybrana/kolizja; *(opcja)* Manual/BCD;
*(opcja)* plakietka PTT; **ikona power Radio Flex** `.flx` na końcu wiersza, `F{s}{0|1}`); karta
**Opis anten** (`.leg` — legenda numer→nazwa); karta **Settings** (`<details>`, zwinięta) z nazwą
stacji, nazwami anten (`.nm`), **edytowalną konfiguracją sieciową** (IP/gateway/maska/DNS, pętla
po 4 polach — oszczędność flash, jak przyciski anten) i **przyciskiem Restart** (`/?R1`, patrz
wyżej). Napięcie **nie jest już** wyświetlane w Settings (usunięte dla oszczędności flash —
ostrzeżenie w topbarze zostaje). Pole nazwy stacji, pętla nazw anten, pętla sieci i przycisk
Restart mają niemal identyczny HTML — generowane przez **wspólne stałe PROGMEM**
(`nmOpen`/`nmMid`/`nmLen11`/`nmClose`, patrz §9 „Watchdog + przycisk Restart") zamiast osobnych
literałów `F()` z tą samą treścią w każdym bloku. Strona odświeża się co 10 s — od 2026-08-02
przez mały inline `<script>` (funkcja `r()`) zamiast dawnego `<meta http-equiv="refresh">`:
przed przeładowaniem sprawdza `document.querySelector('[open]')`
i jeśli którykolwiek `<details>` (czyli karta Settings) jest rozwinięty, odracza sprawdzenie
o 2 s zamiast przeładować — zapobiega zwijaniu Settings i utracie edytowanych, niezapisanych
pól w trakcie edycji (każde pole ma **własny** formularz z osobnym submitem, więc edycja kilku
pól z rzędu mogła nie zmieścić się w 10 s). Split usunięty. **Flash prawie pełny** — przy
zmianach HTML/CSS pilnuj budżetu.

**Wygląd (SQ9FK).** Konwencja designu przeniesiona z projektu
[`rotator_wifi_bridge`](https://github.com/sq9fk/rotator_wifi_bridge): ciemny motyw teal
(tło `#12333b`, karty `#1a3a42`/`#21505c`/`#2a5d6b`), akcent żółty `#f5d33c` (wybrana antena /
Flex WŁ.), alert `#d11534` (kolizja / błąd napięcia), font **Inter** z fallbackiem systemowym
(bez zewnętrznego linku — oszczędza flash i RTT). Zaokrąglone karty (`1.1em`) i przyciski (`.4em`).
Klasy CSS (`bcd/bcdr`, `g/gr`, `ptt`, `nm`, `trx`, `card`, `dot`) współdzielone z symulatorem
[`tools/websim.html`](../tools/websim.html) (`DEVICE_CSS` = lustro `HTTP_HEAD2`).

Podgląd wyglądu bez sprzętu: [`tools/websim.html`](../tools/websim.html) / `python tools/serve.py`.

## 8. Nazwy anten, nazwa stacji, konfiguracja sieciowa i EEPROM

- Domyślne nazwy: `antDefault[]` w PROGMEM. Indeks `0`=`OFF` (**wybieralny zawsze** — antena
  odłączona). Indeks `7` = `M-off->BCD` (**sentinel trybu BCD**) osiągalny **tylko przy `BCD_INPUT`**
  (enkoder 0..7) — pod `#ifdef`, w domyślnym buildzie nie istnieje i nie zajmuje flash. Sentinel
  przesunięty z 8 na 7 → **zlikwidowana martwa luka** po usuniętej 7. antenie (`antRAM` = `[8]`);
  domyślna nazwa stacji: `siteDefault` (`"SQ9FK"`). Radio Flex nie ma nazw (same ikony power).
- Przy `WWW_EEPROM_NAMES`: nazwy anten 1–6 w RAM `antRAM[8][ANT_MAXLEN+1]` oraz **nazwa stacji** w
  `siteRAM[ANT_MAXLEN+1]`, ładowane w `setup()` przez `loadAntNames()` z fallbackiem na domyślne.
  Zapis `saveAntNames()` używa `EEPROM.update` (mniejsze zużycie komórek).
- Przy `EthModule`/`OTRSP_TCP`: **konfiguracja sieciowa** (IP/gateway/maska/DNS) też w EEPROM,
  zamiast na sztywno w kodzie — `netCfg[4]` (wskaźniki na `ip/gateway/subnet/myDns`),
  `loadNetConfig()`/`saveNetConfig()` (zadeklarowane **po** tych zmiennych — `loadAntNames()` nie
  może ich dotykać, bo `IPAddress` tam jeszcze nie istnieje). Ładowane też dla `OTRSP_TCP` (bez
  formularza edycji — gdyby EEPROM miał już zapisane wartości z wcześniejszego flashowania
  wariantu WWW na tym samym urządzeniu).
- **Układ EEPROM (SQ9FK):** bajt `0` = magic `0xA5` (sekcja anten) + 6×`ANT_MAXLEN` (offset `1`);
  bajt `67` = magic `0x5B` (sekcja nazwy stacji) + `ANT_MAXLEN` (nazwa stacji, offset `68`);
  bajt `79` = magic `0x5C` (sekcja sieciowa) + 16 B — 4×4 B (`ip`/`gateway`/`subnet`/`myDns`,
  offset `80`). **Każda sekcja ma własny magic** — wgranie na istniejący EEPROM zachowuje to,
  co już tam było, a nowe sekcje (np. sieciowa na starszym EEPROM) startują z domyślnych.
- Odczyt zawsze przez `antName(idx)` / `siteName()` — zwraca `char*` (RAM) lub
  `__FlashStringHelper*` (PROGMEM) zależnie od flagi; oba typy obsługują `client.print()` i `String`.
  Konfiguracja sieciowa nie ma takiego rozróżnienia — `IPAddress` zawsze w RAM.

## 9. Budżet pamięci i optymalizacje

**Biblioteka Ethernet (2026-07-29):** migracja z `adafruit/Ethernet2` (przestarzała, nieutrzymywana)
na oficjalną `arduino-libraries/Ethernet`. Oficjalna biblioteka jest **większa** — obsługuje
W5100/W5200/W5500 z auto-detekcją chipu w runtime (kod dla wszystkich trzech zawsze skompilowany,
brak `#define`a ograniczającego do samego W5500, w przeciwieństwie do Ethernet2 pisanej wyłącznie
pod W5500). Efekt: **domyślny build (strona WWW) z DHCP przestał się mieścić**, a DHCP przydawało
się tylko w wariantach bez strony WWW — **DHCP zostało w całości usunięte z projektu**
(`__USE_DHCP__`, retry-loop w `setup()`, `Ethernet.maintain()` w `loop()`); IP jest teraz zawsze
statyczne, bez wyjątków.

**Endpoint `/?J`** (2026-07-29, patrz §7) dodał **+68 B** do wszystkich wariantów z `EthModule`
(reużywa `HTTP_HEAD` zamiast nowego literału — koszt to praktycznie tylko warunek + `F("A=")` +
dwa `out.print()` już używane gdzie indziej). Domyślny build: **Flash 99,4 %** (30542 B) —
**zapas ~178 B**. Zmierzono wszystkie 5 wariantów po tej zmianie, wszystkie się mieszczą.

**Endpoint `/?K`** (2026-07-29, patrz §7) dodał kolejne **+72 B** — pętla po 6 nazwach (`antName(k)`)
zamiast dwóch liczb jak w `/?J`, więc drożej mimo tego samego triku (reużycie `HTTP_HEAD`). Domyślny
build: **Flash 99,7 %** (30614 B) — **zapas ~106 B**. To już bardzo mało: kolejna zmiana we
współdzielonym kodzie WWW/OTRSP_TCP może wymagać najpierw znalezienia oszczędności gdzie indziej,
zanim się zmieści. Zmierzono wszystkie 5 wariantów, wszystkie się mieszczą.

**Nazwa stacji w `/?K`** (2026-07-30): rotator_wifi_bridge pokazuje teraz nazwę tego urządzenia przy
nagłówku karty Anteny — dokładnie tak, jak już pokazuje nazwy anten, żywo z urządzenia zamiast
osobnej kopii. Dopisana jako **7. pole** istniejącej odpowiedzi `/?K` (`out.print(',');
out.print(siteName());`) zamiast nowego endpointu — koszt to tylko te dwa wywołania, +16 B (nie
+68 B jak nowy endpoint reużywający `HTTP_HEAD`). Domyślny build: **Flash 99,7 %** (30630 B) —
**zapas ~90 B**. Zmierzono wszystkie trzy warianty z `EthModule` (jedyne, które w ogóle kompilują
handler `/?K`), wszystkie się mieszczą.

**Domyślny build to `EthModule` + `OTRSP_TCP`** (strona WWW + OTRSP po TCP, np. do N1MM+):
**Flash 98,7 %** (30322 B) — **~398 B** zapasu (patrz przegląd bugów 2026-07-29 niżej — było
99,7 %/30630 B, ~90 B, przed tym przeglądem; historia kolejnych zmian tego samego dnia i później
— LCD/auto-odświeżanie, „Settings zostaje rozwinięte"/Serial, siatka mobile, kolizje — patrz
kolejne akapity niżej). To drugi najciaśniejszy z sześciu wariantów (patrz §11; najciaśniejszy
to `EthModule`+`OTRSP`+`OTRSP_TCP` naraz, ~346 B, patrz niżej) i jest teraz domyślny — każda
zmiana we współdzielonym kodzie (WWW HTML/CSS, `OTRSP_parse()`, sieć) musi być
zbudowana i zmierzona na **obu** tych wariantach **najpierw**. Ciekawostka: sam kanał TCP
(`EthernetServer`/`EthernetClient`) kosztuje więcej flash niż kanał USB (`serialEvent()` +
`in_buf`), mimo że intuicyjnie wydawałoby się odwrotnie — kod OTRSP_TCP (parser + bufor + logika
w `loop()`) waży ~968 B. (Uwaga: `EthernetClient::connect(hostname)`/`DNSClient::getHostByName`
— ~1,2 KB martwego kodu ciągniętego przez wirtualną tabelę `EthernetClient` — to koszt **już
obecny w każdym buildzie z `EthernetClient`**, nawet w najlżejszym WWW-bez-OTRSP, nie coś
specyficznego dla `OTRSP_TCP`.) Pierwotny niedobór 42 B odzyskano **poprawką logiki reconnect**
w bloku „OTRSP TCP" (`loop()`, patrz §8) — poprzednia wersja resetowała `otrspClient` przez
`otrspClient = EthernetClient()` zamiast po prostu wołać `.stop()` na starym połączeniu przy
zastąpieniu nowym, co dodatkowo **poprawiło poprawność** (stare gniazdo W5500 jest teraz
zawsze jawnie zamykane). **Oba kanały OTRSP naraz** (`EthModule`+`OTRSP`+`OTRSP_TCP`) — od
2026-08-01 **odblokowane**: **Flash 98,9 %** (30374 B) — zapas ~346 B, patrz niżej.

**`/?J` rozszerzone o stan Radio Flex** (2026-08-03) — rotator_wifi_bridge dostał przycisk PWR
per TRX i musiał znać **prawdziwy** stan `flexState[]`, nie tylko to co ostatnio wysłał (inaczej
po restarcie mostu przycisk pokazywałby zawsze "off" niezależnie od rzeczywistego stanu). Dwa
dodatkowe pola dopisane do istniejącej odpowiedzi `A=...` (ten sam trik co przy nazwie stacji w
`/?K` — dopisanie do istniejącego printa, nie nowy endpoint): `A={ant1},{ant2},{flex1},{flex2}`.
Koszt: **+36 B** na domyślnym wariancie (`EthModule`+`OTRSP_TCP`): **Flash 98,0 %** (30118 B) —
zapas ~602 B. Zmierzony też najciaśniejszy wariant (`EthModule`+`OTRSP`+`OTRSP_TCP`): **Flash
98,3 %** (30206 B) — zapas ~514 B. Oba się mieszczą z zapasem.

**`/?J` rozszerzone o flagę kolizji per TRX** (2026-08-04) — most (rotator_wifi_bridge) liczył
kolizję sam, **symetrycznie**, z samych numerów anten (`ant1==ant2 && ant1!=0`), więc pokazywał
**oba** TRX na czerwono zamiast tylko tego, który faktycznie przegrał — `updateCollisions()` (patrz
wyżej, „Kolizje: 5 poprawek") już liczy to poprawnie i asymetrycznie w `port[i][3]`, tylko nikt
tego nie wysyłał dalej. Dwa kolejne pola dopisane do `A=...`, ten sam trik po raz trzeci:
`A={ant1},{ant2},{flex1},{flex2},{col1},{col2}`. Koszt: **+36 B** na obu zmierzonych wariantach
(taki sam koszt jak Flex wyżej — dwa pola liczbowe 0/1, ta sama struktura printów). Domyślny
(`EthModule`+`OTRSP_TCP`): **Flash 98,8 %** (30358 B) — zapas ~362 B (z ~398 B przed tą zmianą).
Najciaśniejszy (`EthModule`+`OTRSP`+`OTRSP_TCP`): **Flash 99,0 %** (30410 B) — zapas ~310 B (z
~346 B). Oba mieszczą się bez zmian gdzie indziej — zapas płytszy niż przy Flex (wtedy ~514-602 B),
bo międzyczasowe poprawki kolizji (2026-08-03/04, patrz „Kolizje: 5 poprawek") już zjadły część
tamtego zapasu, ale wciąż bezpiecznie ponad 300 B na obu.

**Watchdog + przycisk Restart** (patrz §8) dołożyły **+252 B** do wszystkich wariantów z
`EthModule` (+46 B sam watchdog, wszystkie warianty; +206 B HTML przycisku Restart, tylko
`EthModule`) — domyślny build (wtedy jeszcze bez zapasu, 100,0 %/30716 B) **przestał się
mieścić o 248 B**. Odzyskano **494 B** przez (a) usunięcie wyświetlania napięcia z Settings
(zostało tylko ostrzeżenie — czerwona kropka w topbarze, sama wartość liczbowa nie była
niczym więcej niż ciekawostką) i (b) wydzielenie **wspólnych stałych PROGMEM**
(`nmOpen`/`nmMid`/`nmLen11`/`nmClose`, patrz §7) dla pól Settings — nazwa stacji, pętla nazw
anten i pętla sieci miały niemal identyczny HTML zapisany jako 3 osobne literały `F()` (kompi­
lator NIE scala automatycznie różnych literałów `F()`, nawet jeśli mają wspólne podłańcuchy).
Efekt netto: domyślny build ma teraz **większy zapas niż przed dodaniem watchdoga/Restart**
(246 B vs pierwotne 4 B).

**Przegląd bugów (2026-07-29)** — dogłębny przegląd `main.ino` znalazł i naprawił 6 realnych
błędów: (1) `OTRSP_parse()` — `AUX1n`/`AUX2n` maskowało wartość `& 15` (0-15), ale nigdy nie
walidowało jej względem faktycznego zakresu anten (0-6, lub 0-7 z `BCD_INPUT`) przed zapisem do
`port[idx][1]` — realny OOB-read w `antName()`, osiągalny przez sieć/port szeregowy; naprawione
identyczną walidacją jak już istniała w handlerze WWW; (2) odczyt żądania WWW nie miał timeoutu —
klient, który otworzył połączenie i nic nie wysłał, blokował `loop()` w nieskończoność; dodano
limit 2000 ms; (3) `e`, `enc0Pos` i `Timeout[5][2]` — zmienne czytane w `loop()` a zapisywane w
ISR enkodera (`encI()`) nie były `volatile`; `Timeout` (typ `unsigned long`, 4 B) był dodatkowo
podatny na "torn read" przy przerwaniu w trakcie odczytu; (4) globalny `String Note` w `show()`
(wołane co ~100 ms) zastąpiony stałobuforowym `char noteBuf[]` na stosie — unika fragmentacji
sterty na urządzeniu z 2 KB RAM i długim czasem pracy; **niespodziewany efekt uboczny: odzyskano
~660 B flash**, bo metody `String` (concat/assign/alokacja) ciągną za sobą sporo kodu, nie tylko
RAM; (5) `enc2()` używało globalnego `e` zamiast przekazanego parametru `count` — literówka, która
przy pewnych wywołaniach czytała nieaktualną wartość enkodera; (6) `reqBuf` dla wariantu
`WWW_EEPROM_NAMES` miało 48 B, za mało dla najdłuższego możliwego żądania (edycja pola sieciowego
z pełną nazwą) — zwiększone do 56 B. Efekt na domyślnym buildzie: **Flash 97,0 %** (29810 B) —
**zapas ~910 B** (patrz też §9 niżej) — głównie dzięki (4); (1)/(2)/(6) kosztowały łącznie kilka
do kilkudziesięciu bajtów, (3) i (5) nie mają wpływu na rozmiar. Przy tym zapasie kombinacja
`EthModule`+`OTRSP`+`OTRSP_TCP` (wszystkie trzy naraz) **technicznie już się mieściła**
(zmierzone: 97,3 %, zapas ~824 B) — `#error` blokujący tę kombinację nie został od razu zdjęty
w ramach tego przeglądu (odblokowanie 6. wariantu uznano wtedy za osobną decyzję
architektoniczną), ale **2026-08-01 blokada została usunięta** — patrz §9/§11 niżej.

**LCD splash + auto-odświeżanie WWW (2026-08-02)** — dwie drobne poprawki, **+102 B** łącznie na
wariantach z `EthModule`, **+34 B** na wariantach bez niego: (1) nazwa stacji na LCD była
drukowana zawsze od kolumny 0 (z boku dla nazw krótszych niż 16 znaków) — dodano `siteNameLen()`
i wyliczenie kolumny startowej `(LCDculumn - długość) / 2`, żeby zawsze była wyśrodkowana;
+~28-34 B, dotyczy **wszystkich sześciu** wariantów (kod w `setup()`, nie za `#if EthModule`).
(2) dawny `<meta http-equiv="refresh" content="10;...">` przeładowywał stronę WWW bezwarunkowo
co 10 s, więc rozwinięta karta Settings (`<details>`, stan tylko w DOM przeglądarki, niczym nie
zapisany po stronie urządzenia) zwijała się z powrotem, zanim użytkownik zdążył zapisać zmianę w
polu — każde pole ma **własny** formularz z osobnym submitem, więc edycja kilku pól z rzędu
łatwo przekraczała 10 s. Zastąpione inline `<script>` (jedyny JS w tym projekcie — reszta strony
to czysty HTML/CSS + GET): funkcja `r()` sprawdza `document.querySelector('[open]')` przed
przeładowaniem i jeśli cokolwiek jest rozwinięte, odracza sprawdzenie o 2 s (pętla `setTimeout`)
zamiast przeładować; dotyczy tylko wariantów z `EthModule` (+~68-74 B). Domyślny build po obu
poprawkach: **Flash 97,4 %** (29912 B) — zapas ~808 B; potrójny wariant (`EthModule`+`OTRSP`+
`OTRSP_TCP`): **Flash 97,6 %** (29994 B) — zapas ~726 B. Zmierzono wszystkie sześć wariantów,
wszystkie się mieszczą.

**„Settings zostaje rozwinięte" + awaryjna edycja sieci przez Serial (2026-08-02, tego samego
dnia co wyżej)** — patrz §7 za opis funkcjonalny. Koszt: flaga `settingsOpen` + warunkowy atrybut
`open` (+~186 B na wariantach z `EthModule`, w tym refaktor pętli `N{I|G|M|D}=` w handlerze WWW
do wspólnej `setNetField()`); poszerzenie guardu `serialEvent()`/`in_buf` na warianty (1)/(2) —
`in_buf[64]` **+64 B RAM** tam, gdzie wcześniej nie istniał (bez zmiany na wariantach z `OTRSP`,
gdzie już był kompilowany). Efekt netto na Flash jest **mniejszy niż suma kosztów obu zmian**,
bo `setNetField()` (współdzielona przez WWW i Serial) jest krótsza niż usunięta duplikowana
pętla w handlerze WWW — refaktoryzacja częściowo sfinansowała nową funkcję. Domyślny build:
**Flash 97,9 %** (30082 B) — zapas ~638 B, RAM **55,0 %** (1127 B, +66 B względem stanu przed
tymi dwiema zmianami); potrójny wariant: **Flash 98,2 %** (30168 B) — zapas ~552 B, RAM bez
zmian (1127 B — `in_buf` już tam istniał). Zmierzono wszystkie sześć wariantów, wszystkie się
mieszczą — warianty (5)/(6) (bez `EthModule`) mają guard `serialEvent()` niezmieniony (już
kompilowany przy `OTRSP`), różnica to tylko sama funkcja `setNetField()`/dispatch (+kilkadziesiąt
do ~500 B, zależnie od wariantu — patrz §11), pochłaniana bez trudu przy ich dużych zapasach.

**Siatka anten na mobile (2026-08-02)** — trzy poprawki CSS w `@media(max-width:520px)`: (1)
`.flx` miało `margin-left:auto` (wyrównanie do prawej krawędzi) — gdy power lądował sam z „6" w
krótkim, zawiniętym wierszu, auto-margines wypychał go na sam kraniec, zostawiając wielką dziurę
— usunięte w media query (desktop bez zmian); (2) niewidoczny element `.brk` (`display:none`
domyślnie), wstawiany w HTML tuż przed anteną „4" — na mobile staje się flex-itemem o
`flex-basis:100%; height:0`, wymuszając zawinięcie dokładnie przed „4" (układ 4+4:
`-,1,2,3` / `4,5,6,power` zamiast niekontrolowanego 5+3); wstawka MUSI trafić między zamknięcie
poprzedniego tagu (`">`) a otwarcie kolejnego `<input>` — pętla generująca przyciski odracza
zamknięcie `class="..."` do początku NASTĘPNEJ iteracji (oszczędność literału), więc naiwne
wstawienie przed `if(pos==0){...}else{...}` ląduje w NIEZAMKNIĘTYM atrybucie; (3)
`.trx input[type=submit],.trx .flx{flex:1 1 0}` — oba wiersze wypełniają całą szerokość karty
równymi przyciskami. Koszt: +186 B (default), zmierzone kumulatywnie z poprawkami kolizji niżej.

**Kolizje: 5 poprawek (2026-08-03/04)** — patrz §4 i §7 za opis logiki/UI. (1) dodatkowe wywołanie
`updateCollisions()` zaraz po `port[bankIdx][1]=getVal` w handlerze WWW (staly kolor po
przeładowaniu); (2) `port[i][1] != 0 &&` w warunku kolizji (fałszywe OFF+OFF); (3) atrybucja
kolizji tylko TRX, który się przełączył (request-vs-output, nie request-vs-request); (4) górny
chip statusu pokazuje `.sq.r` + „OFF" zamiast żółtego + nazwy żądania, gdy `port[i][3]==1`; (5)
**dwa przebiegi** wewnątrz `updateCollisions()` (`for (byte pass=0; pass<2; pass++)`) — w jednym
przebiegu TRX o niższym indeksie widziałby wyjście TRX o wyższym indeksie SPRZED tego wywołania,
więc zablokowany TRX o niższym indeksie nie odzyskiwał anteny w TYM SAMYM kliknięciu, gdy
„wygrany" TRX o wyższym indeksie ją zwalniał (dopiero po ręcznym odświeżeniu — prawdziwy bug
zgłoszony przez użytkownika po tym, jak punkt (3) zadziałał poprawnie tylko dla JEDNEGO kierunku
indeksów). Drugi przebieg (używający już w pełni świeżych wyjść z przebiegu 1) usuwa tę
zależność od kolejności — zweryfikowane skryptem `collision_trace.py` (cztery scenariusze,
odwrócona kolejność kliknięć i indeksów). Ten sam problem i fix zastosowany w `websim.html`
(`recalcErr()` też opakowane w `for (pass...)`, plus wcześniej przepisane z symetrycznego
`sel===sel` na `sel!==0 && sel===state.port[j].out` + trwały `out` per port). Domyślny build po
wszystkich poprawkach mobile+kolizje: **Flash 98,7 %** (30322 B) — zapas ~398 B, RAM **55,0 %**
(1127 B); potrójny wariant: **Flash 98,9 %** (30374 B) — zapas ~346 B. Zmierzono wszystkie
sześć wariantów, wszystkie się mieszczą.

**Strona WWW bez OTRSP** (`EthModule` samo, static IP edytowalna przez WWW) — bezpieczniejszy
wybór z dużym zapasem, jeśli OTRSP-TCP nie jest potrzebne: **Flash 95,7 %** (29394 B), ~1,3 KB
wolne. **`EthModule` + `OTRSP`** (USB, bez TCP): **Flash 97,1 %** (29822 B) — zapas ~898 B.
Build z wszystkim WŁ. (BCD+PTT+strona WWW) **już się nie mieści** niezależnie od wariantu OTRSP.

**Sama strona WWW kosztuje ~8 KB flash** (HTML/CSS/`BufP`/print-y w bloku obsługi klienta) — nie
sam Ethernet. Bez WWW: `OTRSP` po USB (bez TCP, bez Ethernetu) = **33,7 %** (10340 B, bez
konfiguracji sieciowej — brak `EthModule`/`OTRSP_TCP` — więc bez komend Serial `N{IGMD}=`);
+ `OTRSP_TCP` (USB+TCP równolegle) = **69,7 %** (21412 B).

*Historia (przed usunięciem DHCP z projektu):* DHCP kosztowało dodatkowo ~3,8 KB
(`Dhcp.cpp`+`EthernetUdp.cpp`, niewyłączalne osobno od reszty biblioteki). Strona WWW + DHCP
razem = **106,3 %** (32650 B) — **nie mieściło się**, co był głównym powodem, dla którego DHCP
było domyślnie wyłączone dla `EthModule`, a docelowo — skoro dawało realną korzyść tylko
w wariancie `OTRSP`+`OTRSP_TCP` bez WWW (tam był zapas ~5,3 KB) — usunięte z projektu w całości
zamiast trzymane jako opcja dla jednego przypadku.

Zastosowane techniki (patrz komentarze `//SQ9FK`):
- tablice stałe w **PROGMEM** (`antDefault`, `glyphs`, `BCDmatrixOUT`), `port[8][6]` jako `byte`;
- generowanie przycisków WWW i listy nazw w **pętli** (mniej powtórzonych łańcuchów `F()`);
  konfiguracja sieciowa (IP/gateway/maska/DNS) tym samym wzorcem (`netCfg[4]` + PROGMEM etykiety
  `netLbl[]`/`netCode[]`) zamiast 4 rozwiniętych bloków — istotne przy ~246 B zapasu domyślnego
  buildu;
- **wspólne stałe PROGMEM dla pól Settings** (`nmOpen`/`nmMid`/`nmLen11`/`nmClose`) — nazwa
  stacji, pętla nazw anten, pętla sieci i przycisk Restart miały niemal identyczny HTML
  zapisany jako osobne literały `F()` (kompilator NIE scala różnych literałów `F()`, nawet
  z identycznymi podłańcuchami) — odzyskano ~440 B;
- **`BufP`** — buforowanie **całego** wyjścia strony (RAM, porcje 128 B) zamiast per-znak `send()`
  do W5500: kilkadziesiąt segmentów TCP zamiast tysiąca → **znacznie szybsze wyświetlanie** i krótsza
  blokada `loop()`. Static (nagłówek/CSS/ikona) i dynamiczny HTML tym samym buforem;
- **batchowany odczyt żądania** — `client.read(buf,len)` (`recv`) + `memchr('\n')` zamiast po bajcie;
- parsowanie żądań **bez `String`** (bufor `char`), walidacja zakresu (brak zapisu poza `port[]`);
- czytanie tylko pierwszej linii żądania.

BCD/PTT/OTRSP/OTRSP_TCP jako `#ifdef` — wyłączone nie zajmują flash/RAM.

## 10. Mapa `#ifdef` (gdzie szukać przy zmianach)

| Funkcja | Miejsca w kodzie |
|---|---|
| `EthModule` \| `OTRSP_TCP` | mac/ip/gateway/subnet + `Ethernet.begin(mac,ip,myDns,gateway,subnet)` w `setup()` — **wspólne** dla obu |
| `EthModule` | `server(80)`, `HTTP_HEAD*`, `POWER_SVG`, `BufP`, sekcja serwera WWW w `loop()` |
| `OTRSP_TCP` | `otrspServer`/`otrspClient`/`otrsp_tcp_buf`/`otrsp_tcp_len`, sekcja „OTRSP TCP" w `loop()` |
| `WWW_EEPROM_NAMES` | deklaracja `antRAM`/`siteRAM`/`antName`/`siteName`/EEPROM, `setup()` (`loadAntNames`), parser (`N`/`NS`) i formularze Settings, rozmiar `reqBuf` |
| `BCD_INPUT` | `BCDmatrixOUT`, gałąź auto w `loop()`, zakres enkodera, przyciski Manual/BCD w WWW, pozycja „7" w `show()`, cała funkcja `rx()` |
| `PTT_BLOCKING` | warunki `if(port[i][2]==0)` w `loop()`, plakietka PTT w `show()` i WWW, odczyt PTT w `rx()` |
| `OTRSP` \| `OTRSP_TCP` | `OTRSP_parse(char*,Print&)` — wspólne dla obu (`#if defined(OTRSP) \|\| defined(OTRSP_TCP)`) |
| `OTRSP` \| (`WWW_EEPROM_NAMES` && (`EthModule`\|`OTRSP_TCP`)) | deklaracja `in_buf`/`in_len`/`stringComplete`, `serialEvent()` — kanał USB dla OTRSP ORAZ/LUB awaryjnej edycji sieci (`N{IGMD}=`), patrz `setNetField()` niżej |
| `WWW_EEPROM_NAMES` && (`EthModule`\|`OTRSP_TCP`) | `netCfg`/`netCode`/`parseIPField()`/`setNetField()` — współdzielone przez formularz WWW (`N{I\|G\|M\|D}=`) i komendy Serial (`N{IGMD}=\r`) |

> Wykrywanie kolizji między TRX jest **osobne** od `PTT_BLOCKING` i działa zawsze.

## 11. Weryfikacja

- Kompilacja: `pio run -e nanoatmega328` (0 ostrzeżeń z naszego kodu; ostrzeżenia z biblioteki
  `Ethernet` są nieszkodliwe). Warto też zbudować z `-DBCD_INPUT -DPTT_BLOCKING` — razem ze
  stroną WWW **nie mieści się**; sprawdzaj te gałęzie bez `EthModule`.
- **Sześć wariantów do sprawdzenia przy zmianach w Ethernet/OTRSP:** (1) **domyślny** —
  `#define EthModule` + `//#define OTRSP` + `#define OTRSP_TCP` (WWW + OTRSP po TCP,
  **98,7% — zapas ~398 B**) — buduj i mierz TĘ gałąź **najpierw**, przy dosłownie
  każdej zmianie w WWW/CSS/OTRSP_TCP/sieci, bo trafia do każdego kto skompiluje projekt bez
  ruszania `#define`; (2) `#define EthModule` + `//#define OTRSP` + `//#define OTRSP_TCP`
  (strona WWW bez OTRSP, static IP, 95,7%, zapas ~1,3 KB — bezpieczniejsza alternatywa); (3)
  `#define EthModule` + `#define OTRSP` + `//#define OTRSP_TCP` (WWW + OTRSP po USB, 97,1%);
  (4) `#define EthModule` + `#define OTRSP` + `#define OTRSP_TCP` (WWW + OTRSP po USB **i** TCP
  naraz, **98,9% — zapas ~346 B**, najciaśniejszy ze wszystkich sześciu — buduj i mierz też TĘ
  gałąź **od razu po** wariancie (1), odblokowana 2026-08-01, dawny `#error` usunięty); (5)
  `#define OTRSP` + `//#define EthModule` (USB, bez Ethernetu, 33,7%, bez konfiguracji
  sieciowej — brak komend Serial `N{IGMD}=`); (6) `#define OTRSP`
  + `#define OTRSP_TCP` + `//#define EthModule` (USB+TCP równolegle, bez WWW, 69,7%).
- Testy funkcjonalne (W5500, EEPROM, przełączanie, klient OTRSP przez TCP) — na docelowej
  stacji (brak sprzętu w CI).

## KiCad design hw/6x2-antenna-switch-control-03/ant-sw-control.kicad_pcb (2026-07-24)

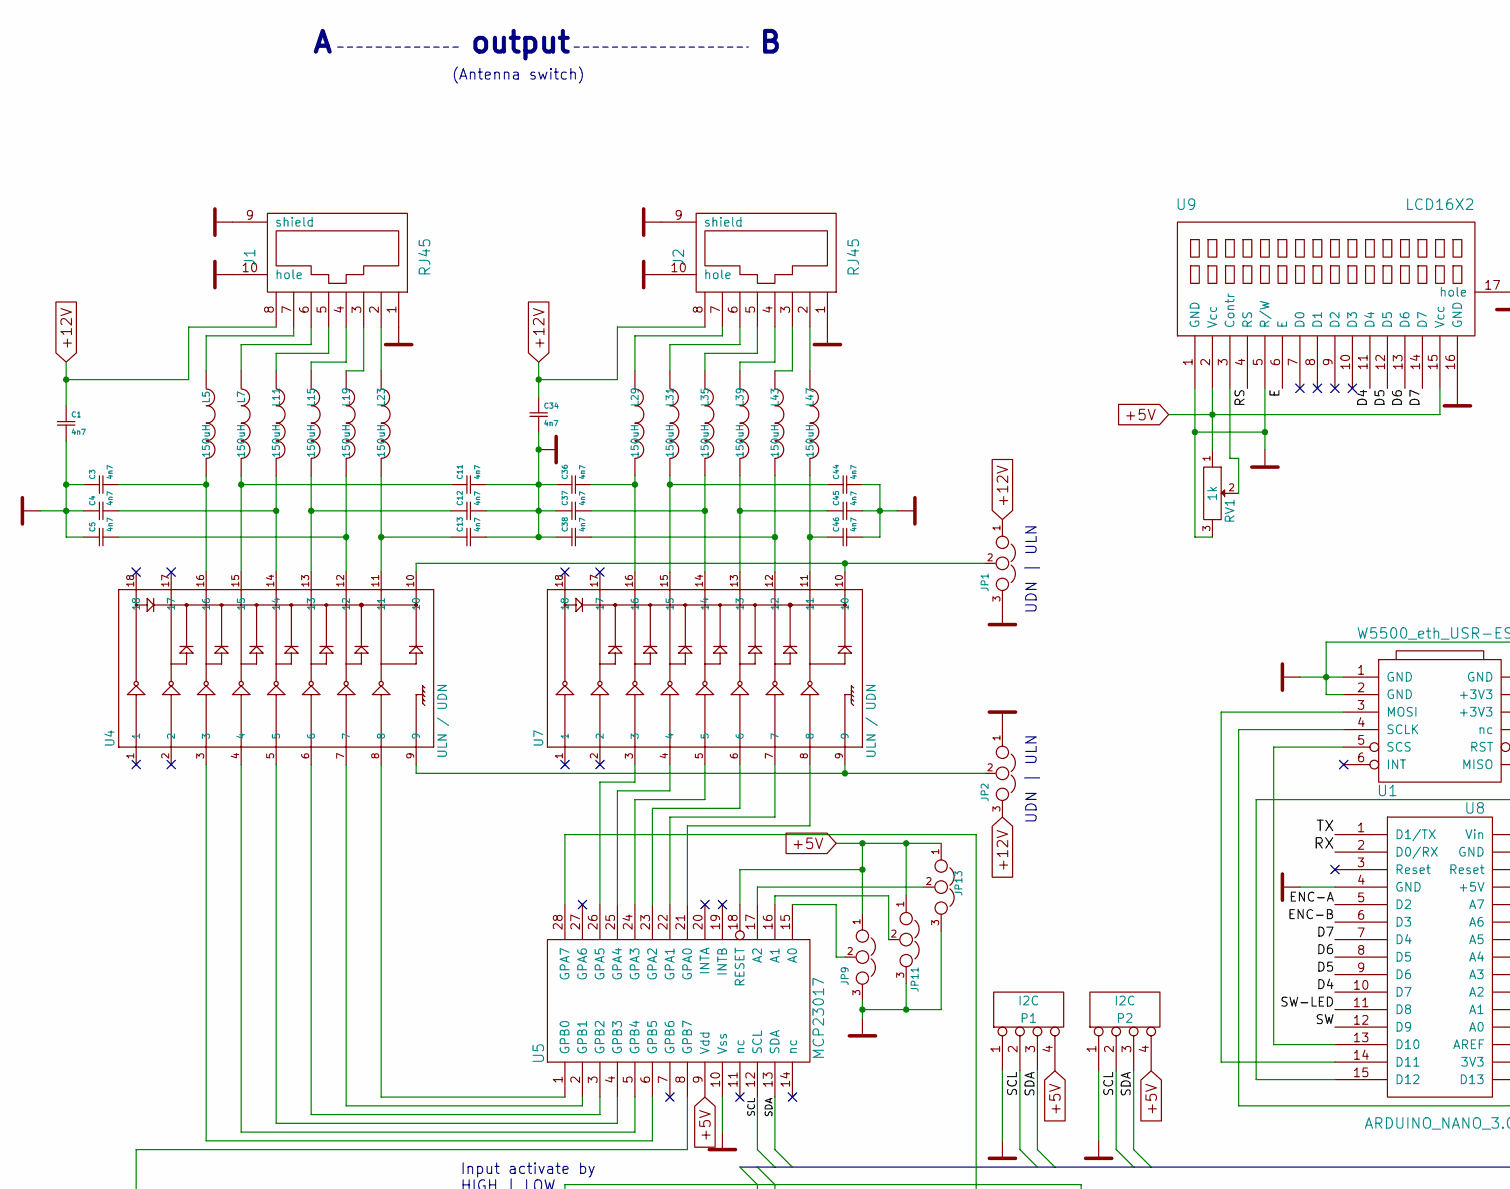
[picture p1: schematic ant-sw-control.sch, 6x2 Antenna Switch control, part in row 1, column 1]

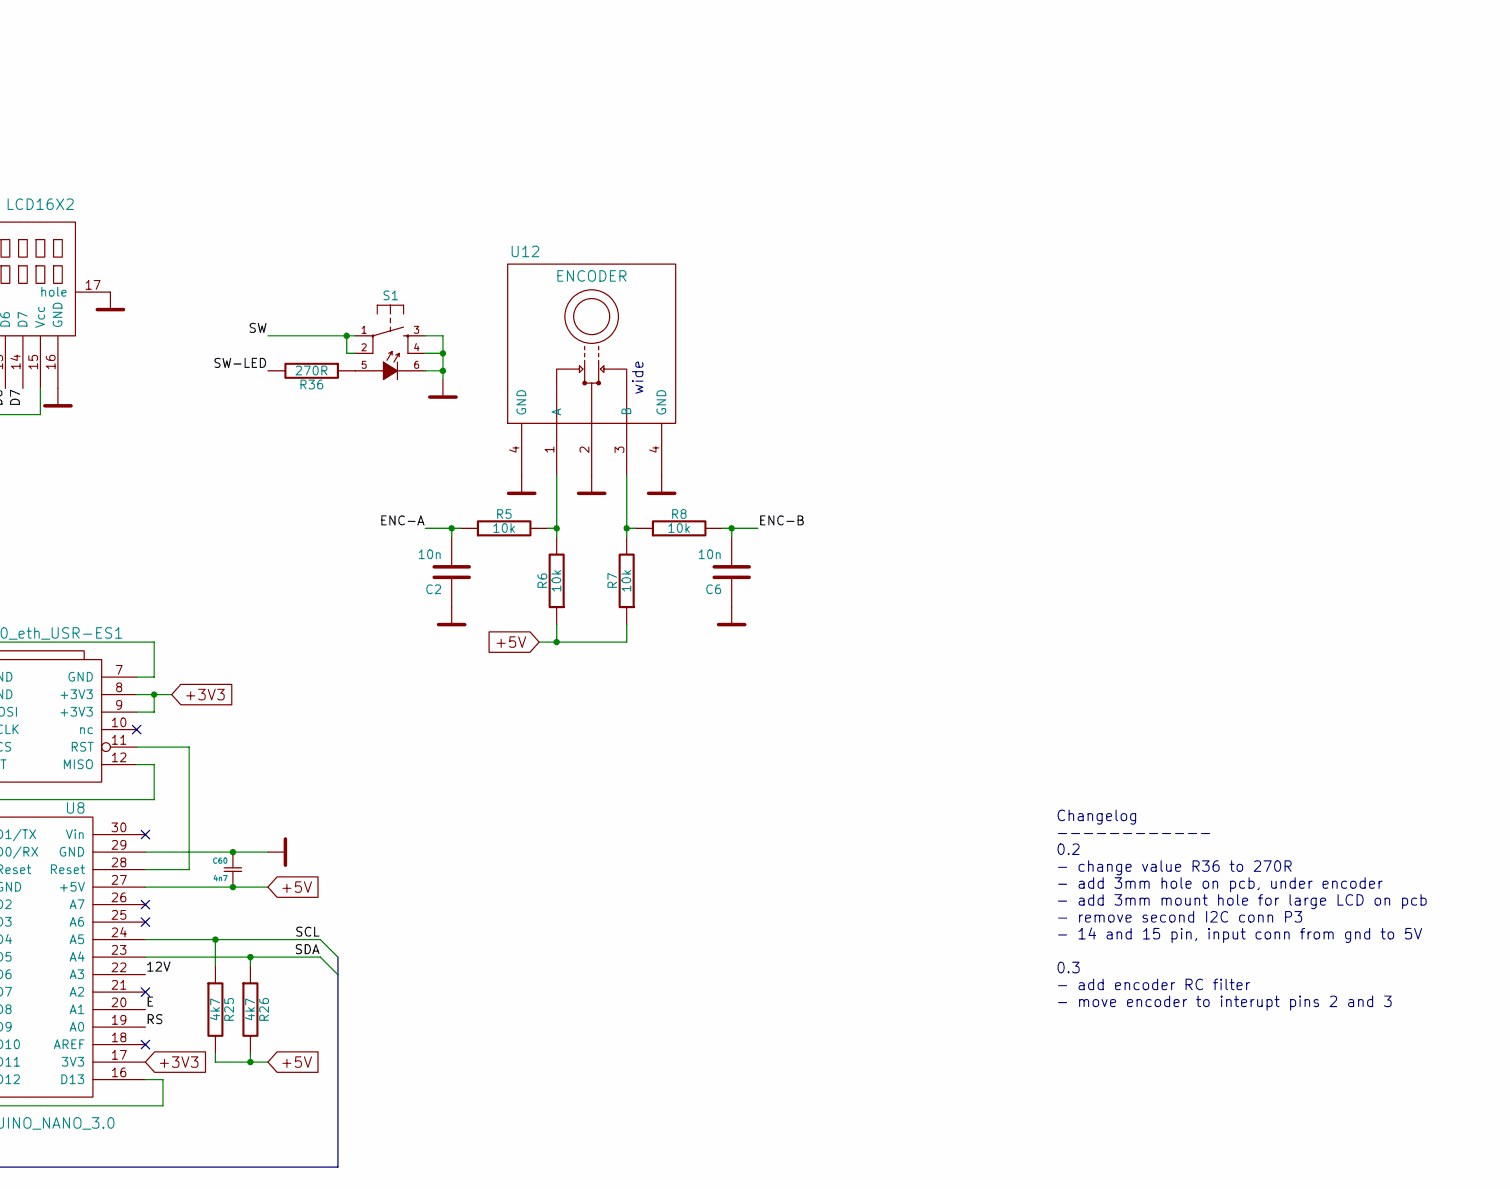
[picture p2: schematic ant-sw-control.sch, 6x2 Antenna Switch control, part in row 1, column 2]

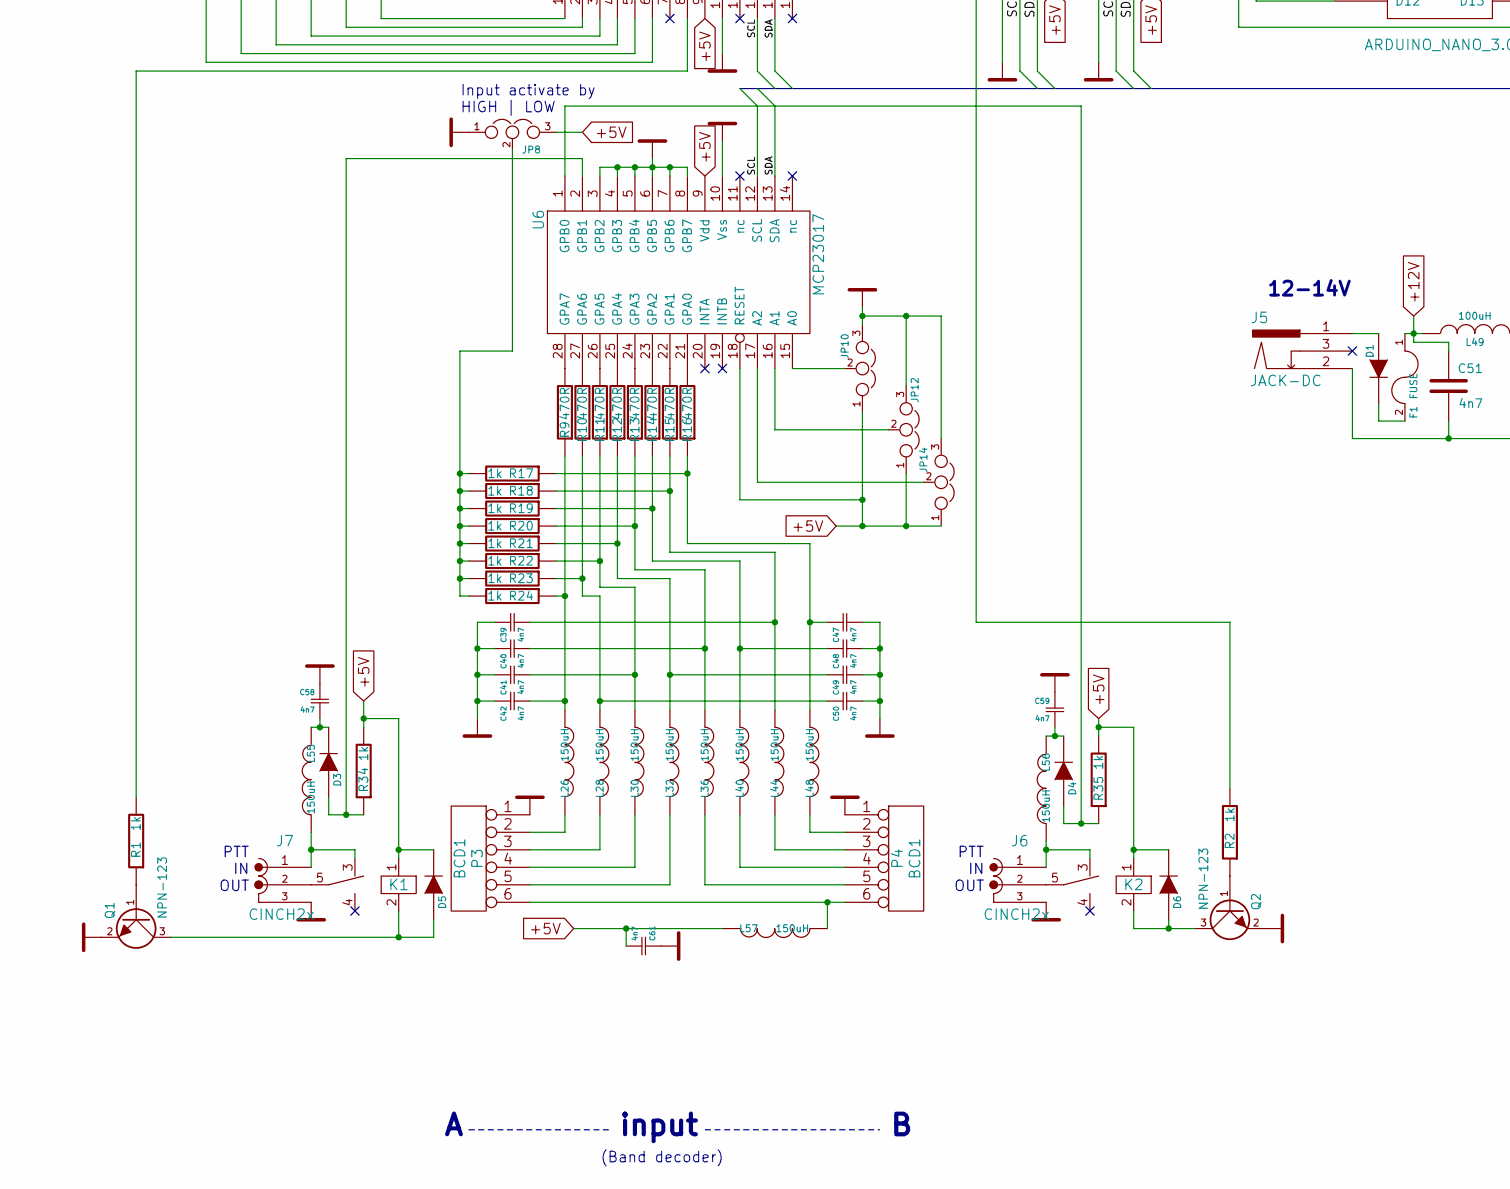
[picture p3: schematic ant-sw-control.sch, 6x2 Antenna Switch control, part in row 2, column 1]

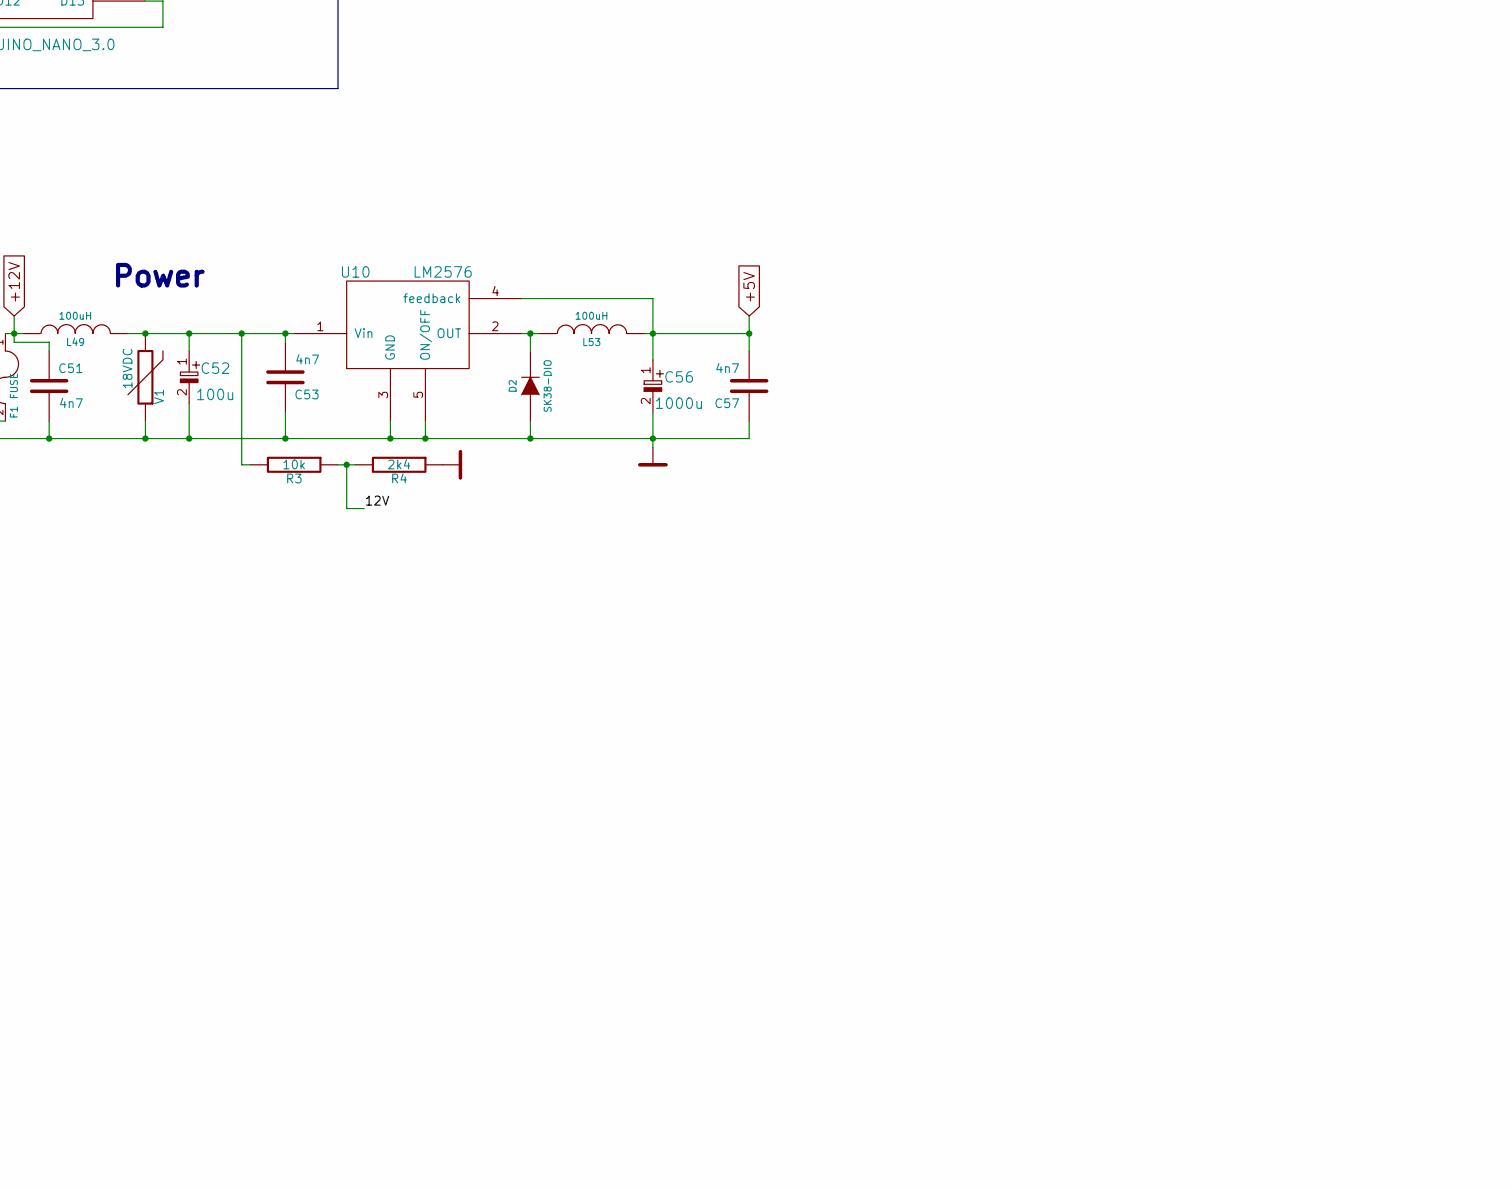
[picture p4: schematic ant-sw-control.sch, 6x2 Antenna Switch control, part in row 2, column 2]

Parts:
C1, C3, C4, C5, C11, C12, C13, C34, C36, C37, C38, C39, C40, C41, C42, C44, C45, C46, C47, C48, C49, C50, C51, C53, C57, C58, C59, C60, C61: 4n7; SMD0805
C2, C6: 10n; SMD0805
C52: 100u; SMDHD-VF-6.3
C56: 1000u; SMDHD-VF
D1, D2: SK38-DIO; DO-214AB
D3, D4, D5, D6: BAS85.115; MiniMELF
F1: FUSE; SM1812
J1, J2: RJ45
J5: JACK-DC; jack-dc
J6, J7: CINCH2x; cinch-RCA-2x
JP1, JP2, JP8: JUMPER3; SIL-3
JP9, JP10, JP11, JP12, JP13, JP14: JUMPER3; SMD0805-3-jumper
K1, K2: REL-RSY
L5, L7, L11, L15, L19, L23, L26, L28, L29, L30, L31, L32, L35, L36, L39, L40, L43, L44, L47, L48, L55, L56, L57: 150uH; SM1210
L49: 100uH; L-DE0703
L53: 100uH; L-SELF-WE-PD-XXL
P1, P2: I2C; SIL-4
P3, P4: BCD1; RJ12
Q1, Q2: NPN-123; SOT23
R1, R2, R17, R18, R19, R20, R21, R22, R23, R24, R34, R35: 1k; SMD0805
R3, R5, R6, R7, R8: 10k; SMD0805
R4: 2k4; SMD0805
R9, R10, R11, R12, R13, R14, R15, R16: 470R; SMD0805
R25, R26: 4k7; SMD0805
R36: 270R; SMD0805
RV1: 1k; POT63YA
S1: KS01-BL-tact-led; tact-led-pb6156
U1: W5500_eth_USR-ES1; ETH-W5500-usr-es1
U4, U7: ULN / UDN; DIP-18
U5, U6: MCP23017; SO28
U8: ARDUINO_NANO_3.0; ArduinoNano3.0
U9: LCD16X2; LCD-16x2-vert-mount
U10: LM2576; TO-263-5
U12: ENCODER; Encoder-ED16112O-vert
V1: 18VDC; SMD0805

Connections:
+3V3: U1.8 (+3V3), U1.9 (+3V3), U8.17 (3V3)
+5V: C56.1, C57.2, C60.2, C61.2, D5.2 (K), D6.2 (K), JP8.3, JP9.1, JP10.1, JP11.1, JP12.1, JP13.1, JP14.1, K1.1, K2.1, L53.2, L57.1, P1.4, P2.4, R6.1, R7.1, R25.2, R26.2, R34.2, R35.2, RV1.1, U5.9 (Vdd), U5.18 (RESET), U6.9 (Vdd), U6.18 (RESET), U8.27 (+5V), U9.2 (Vcc), U9.15 (Vcc), U10.4 (feedback)
+12V: C1.1, C34.1, C51.1, F1.1, J1.8, J2.8, JP1.1, JP2.3, L49.1
/12V: R3.1, R4.2, U8.22 (A3)
/D4: U8.10 (D7), U9.11 (D4)
/D5: U8.9 (D6), U9.12 (D5)
/D6: U8.8 (D5), U9.13 (D6)
/D7: U8.7 (D4), U9.14 (D7)
/E: U8.20 (A1), U9.6 (E)
/ENC-A: C2.2, R5.1, U8.5 (D2)
/ENC-B: C6.2, R8.2, U8.6 (D3)
/RS: U8.19 (A0), U9.4 (RS)
/SCL: P1.2, P2.2, R25.1, U5.12 (SCL), U6.12 (SCL), U8.24 (A5)
/SDA: P1.3, P2.3, R26.1, U5.13 (SDA), U6.13 (SDA), U8.23 (A4)
/SW: S1.1, S1.2, U8.12 (D9)
/SW-LED: R36.2, U8.11 (D8)
GND: C1.2, C2.1, C3.1, C4.1, C5.1, C6.1, C11.2, C12.2, C13.2, C34.2, C36.1, C37.1, C38.1, C39.1, C40.1, C41.1, C42.1, C44.2, C45.2, C46.2, C47.2, C48.2, C49.2, C50.2, C51.2, C52.2, C53.1, C56.2, C57.1, C58.1, C59.1, C60.1, C61.1, D2.1 (A), J1.1, J1.9 (shield), J1.10 (hole), J2.1, J2.9 (shield), J2.10 (hole), J5.2, J6.3, J7.3, JP1.3, JP2.1, JP8.1, JP9.3, JP10.3, JP11.3, JP12.3, JP13.3, JP14.3, P1.1, P2.1, P3.1, P4.1, Q1.2, Q2.2, R4.1, RV1.3, S1.3, S1.4, S1.6, U1.1 (GND), U1.2 (GND), U1.7 (GND), U5.10 (Vss), U6.3 (GPB2), U6.4 (GPB3), U6.5 (GPB4), U6.6 (GPB5), U6.7 (GPB6), U6.8 (GPB7), U6.10 (Vss), U8.4 (GND), U8.29 (GND), U9.1 (GND), U9.5 (R/W), U9.16 (GND), U9.17 (hole), U10.3 (GND), U10.5 (ON/OFF), U12.2, U12.4 (GND), V1.1
unnamed: C3.2, L5.2, U4.16
unnamed: C4.2, L11.2, U4.14
unnamed: C5.2, L19.2, U4.12
unnamed: C11.1, L7.2, U4.15
unnamed: C12.1, L15.2, U4.13
unnamed: C13.1, L23.2, U4.11
unnamed: C36.2, L29.2, U7.16
unnamed: C37.2, L35.2, U7.14
unnamed: C38.2, L43.2, U7.12
unnamed: C39.2, L44.2, R15.1, R18.1
unnamed: C40.2, L36.2, R13.1, R20.1
unnamed: C41.2, L30.2, R11.1, R22.1
unnamed: C42.2, L26.2, R9.1, R24.1
unnamed: C44.1, L31.2, U7.15
unnamed: C45.1, L39.2, U7.13
unnamed: C46.1, L47.2, U7.11
unnamed: C47.1, L48.2, R16.1, R17.1
unnamed: C48.1, L40.2, R14.1, R19.1
unnamed: C49.1, L32.2, R12.1, R21.1
unnamed: C50.1, L28.2, R10.1, R23.1
unnamed: C52.1, C53.2, L49.2, R3.2, U10.1 (Vin), V1.2
unnamed: C58.2, D3.2 (K), L55.1
unnamed: C59.2, D4.2 (K), L56.1
unnamed: D1.1 (A), J5.1
unnamed: D1.2 (K), F1.2
unnamed: D2.2 (K), L53.1, U10.2 (OUT)
unnamed: D3.1 (A), R34.1, U6.2 (GPB1)
unnamed: D4.1 (A), R35.1, U6.1 (GPB0)
unnamed: D5.1 (A), K1.2, Q1.3
unnamed: D6.1 (A), K2.2, Q2.3
unnamed: J1.2, L23.1
unnamed: J1.3, L19.1
unnamed: J1.4, L15.1
unnamed: J1.5, L11.1
unnamed: J1.6, L7.1
unnamed: J1.7, L5.1
unnamed: J2.2, L47.1
unnamed: J2.3, L43.1
unnamed: J2.4, L39.1
unnamed: J2.5, L35.1
unnamed: J2.6, L31.1
unnamed: J2.7, L29.1
unnamed: J6.1, K2.3, L56.2
unnamed: J6.2, K2.5
unnamed: J7.1, K1.3, L55.2
unnamed: J7.2, K1.5
unnamed: JP1.2, U4.10, U7.10
unnamed: JP2.2, U4.9, U7.9
unnamed: JP8.2, R17.2, R18.2, R19.2, R20.2, R21.2, R22.2, R23.2, R24.2
unnamed: JP9.2, U5.15 (A0)
unnamed: JP10.2, U6.15 (A0)
unnamed: JP11.2, U5.16 (A1)
unnamed: JP12.2, U6.16 (A1)
unnamed: JP13.2, U5.17 (A2)
unnamed: JP14.2, U6.17 (A2)
unnamed: L26.1, P3.2
unnamed: L28.1, P3.3
unnamed: L30.1, P3.4
unnamed: L32.1, P3.5
unnamed: L36.1, P4.5
unnamed: L40.1, P4.4
unnamed: L44.1, P4.3
unnamed: L48.1, P4.2
unnamed: L57.2, P3.6, P4.6
unnamed: Q1.1, R1.1
unnamed: Q2.1, R2.1
unnamed: R1.2, U5.8 (GPB7)
unnamed: R2.2, U5.28 (GPA7)
unnamed: R5.2, R6.2, U12.1 (A)
unnamed: R7.2, R8.1, U12.3 (B)
unnamed: R9.2, U6.28 (GPA7)
unnamed: R10.2, U6.27 (GPA6)
unnamed: R11.2, U6.26 (GPA5)
unnamed: R12.2, U6.25 (GPA4)
unnamed: R13.2, U6.24 (GPA3)
unnamed: R14.2, U6.23 (GPA2)
unnamed: R15.2, U6.22 (GPA1)
unnamed: R16.2, U6.21 (GPA0)
unnamed: R36.1, S1.5
unnamed: RV1.2, U9.3 (Contr)
unnamed: U1.3 (MOSI), U8.14 (D11)
unnamed: U1.4 (SCLK), U8.16 (D13)
unnamed: U1.5 (SCS), U8.13 (D10)
unnamed: U1.11 (RST), U8.28 (Reset)
unnamed: U1.12 (MISO), U8.15 (D12)
unnamed: U4.3, U5.6 (GPB5)
unnamed: U4.4, U5.5 (GPB4)
unnamed: U4.5, U5.4 (GPB3)
unnamed: U4.6, U5.3 (GPB2)
unnamed: U4.7, U5.2 (GPB1)
unnamed: U4.8, U5.1 (GPB0)
unnamed: U5.21 (GPA0), U7.8
unnamed: U5.22 (GPA1), U7.7
unnamed: U5.23 (GPA2), U7.6
unnamed: U5.24 (GPA3), U7.5
unnamed: U5.25 (GPA4), U7.4
unnamed: U5.26 (GPA5), U7.3

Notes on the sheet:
12-14V
Power
output
input
Input activate by HIGH | LOW
(Band decoder)
PTT IN OUT
(Antenna switch)
Changelog ------------ 0.2 - change value R36 to 270R - add 3mm hole on pcb, under encoder - add 3mm mount hole for large LCD on pcb - remove second I2C conn P3 - 14 and 15 pin, input conn from gnd to 5V 0.3 - add encoder RC filter - move encoder to interupt pins 2 and 3
UDN | ULN
wide

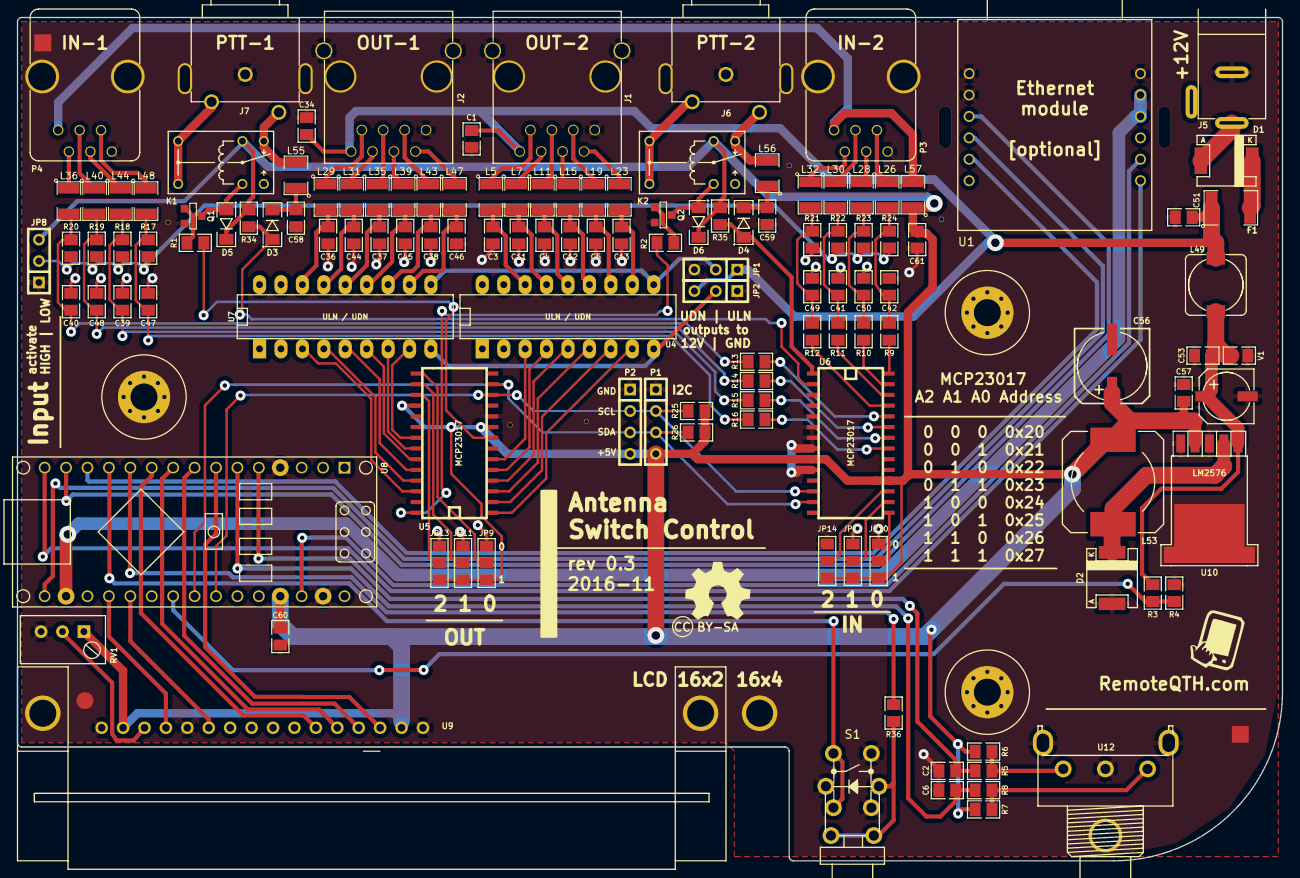
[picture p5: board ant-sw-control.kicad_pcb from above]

Board: 2 copper layers, 150.0 x 100.0 mm, 140 parts (0 on the bottom side), 114 nets.

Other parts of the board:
Ref**: Val**; 3.2mm
Ref**#2, Ref**#3: Val**; 3.2mm
prokovka: VAL**; prokovka
prokovka#2, prokovka#3, prokovka#4, prokovka#5, prokovka#6: VAL**; prokovka-0.5
prokovka#7, prokovka#8, prokovka#9: VAL**; prokovka

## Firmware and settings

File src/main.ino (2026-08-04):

#include <Arduino.h>   // jawne dla IntelliSense (build .ino i tak go docieka; naprawia falszywy blad PROGMEM w VS Code)
#include <avr/wdt.h>   // SQ9FK: watchdog - reset przy zawieszeniu (patrz setup()/loop()) + restart z WWW

/*

  6 x 2 Antenna control
  ----------------------
  http://remoteqth.com/6x2-antenna-controler.php
  2016-12 by OK1HRA
  rev 0.3

  ___               _        ___ _____ _  _
  | _ \___ _ __  ___| |_ ___ / _ \_   _| || |  __ ___ _ __
  |   / -_) '  \/ _ \  _/ -_) (_) || | | __ |_/ _/ _ \ '  \
  |_|_\___|_|_|_\___/\__\___|\__\_\|_| |_||_(_)__\___/_|_|_|


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
  Features:
  INPUTS
    - Four TRX
    - Automatic four bit BCD - may be activate LOW or HIGH, must be configure on pcb and firmware
    - Manual menu with light button and rotary encoder
    - Manually through the web interface
    - Free configure matrix input table
  OUTPUTS
    - 6 antennas
    - 2x6 gpio outputs (12V or GND output dependancy to use IO driver)
    - serialline
    - web page
  BLOCKED
    - more inpunts in same time = select only one antenna for each TRX
    - colision between TRX and same antenna
    - switching during PTT ON, separately for each TRX
    - interruption PTT path if colision detected
  SHOW on LCD/WEB
    - active number outputs
    - colision
    - PTT ON
    - name of the antenna
    - power voltage
  ETHERNET (with optional IP module)
    - DHCP
    - fixed IP
    - Show IP on LCD during start up
  - refresh input < 25 ms two TRX, < 55 ms four TRX (arduino Nano)
  - all mounted on compact pcb - useable without enclosure
  - output connector included power for switch - all in one cable
  - Ethernet hardware support
  - support two line LCD, one for each TRX
  - measure input voltage
  
  Changelog:
  2016-12 change to rev 0.3 pinout

  SQ9FK: DHCP usuniete z projektu (2026-07-29) - IP jest zawsze statyczne, edytowalne przez
  WWW+EEPROM (patrz netCfg[] w setup()). Powod: DHCP kosztuje ~3,8 KB flash z oficjalna
  biblioteka arduino-libraries/Ethernet, a przy stronie WWW budzet ATmega328 tego nie miesci.


  
*/
//=====[ Settings ]===================================================
// ---- Funkcje opcjonalne (SQ9FK) -------------------------------------------
//#define BCD_INPUT        // automatyczny wybor anteny z BCD radia (wejscia MCP IN) - WYLACZONE
//#define PTT_BLOCKING     // odczyt PTT + blokada przelaczania podczas TX - WYLACZONE
#define WWW_EEPROM_NAMES      // edycja nazw anten, stacji, IP/gateway/maski/DNS przez WWW + zapis w EEPROM (wymaga EthModule)
#define ANT_MAXLEN 11      // limit dlugosci nazwy anteny (mieści sie na LCD: LCDculumn-5)

// Domyslne nazwy anten (zrodlo inicjalizacji). Indeks 0 nieedytowalny (OFF); 7 = sentinel trybu BCD.
const char ant_0[] PROGMEM = "OFF";          // <-- do not change this line
const char ant_1[] PROGMEM = "ANT1";
const char ant_2[] PROGMEM = "ANT2";
const char ant_3[] PROGMEM = "ANT3";
const char ant_4[] PROGMEM = "ANT4";
const char ant_5[] PROGMEM = "ANT5";
const char ant_6[] PROGMEM = "ANT6";
#if defined(BCD_INPUT)
// SQ9FK: poz. 7 = sentinel trybu BCD ("M-off->BCD"), osiagalna tylko przy BCD_INPUT (enkoder 0..7).
// Sentinel przesuniety z 8 na 7 -> zlikwidowana martwa luka (dawna poz. 7 po usunietej 7. antenie).
const char ant_7[] PROGMEM = "M-off->BCD";
#endif
const char* const antDefault[] PROGMEM = {
  ant_0, ant_1, ant_2, ant_3, ant_4, ant_5, ant_6,
#if defined(BCD_INPUT)
  ant_7,                                     // sentinel trybu BCD (poz. 7) - tylko gdy BCD_INPUT
#endif
};
// SQ9FK: dwa niezalezne wyjscia Radio Flex na GPA7 (K1/J7) i GPB7 (K2/J6) - dawniej przekaznik
// pasma GXP11 40m. Sterowane osobnymi ikonami power w wierszach TRX (WWW), bez nazw.
// Domyslna nazwa stacji (topbar), edytowalna przez WWW i zapisywana w EEPROM:
const char siteDefault[] PROGMEM = "SQ9FK";
#if defined(WWW_EEPROM_NAMES)
  #include <EEPROM.h>
  #define ANT_EE_MAGIC  0xA5                         // magic sekcji nazw anten 1..6 (bez zmian -> nazwy zachowane)
  // SQ9FK: sekcja nazwy stacji ma WLASNY magic (za 6 nazwami anten). Dzieki temu przy zachowaniu
  // starego EEPROM (magic 0xA5) nazwy anten 1..6 zostaja, a nazwa stacji startuje z domyslnej.
  #define SITE_EE_MAGIC 0x5B
  #define SITE_MAG_OFF  (1 + 6 * ANT_MAXLEN)         // 67: bajt-magic sekcji nazwy stacji
  #define SITE_EE_OFF   (SITE_MAG_OFF + 1)           // 68: nazwa stacji
  char antRAM[8][ANT_MAXLEN + 1];            // 0=OFF, 1..6 anteny, 7=sentinel BCD (tylko BCD_INPUT)
  char siteRAM[ANT_MAXLEN + 1];              // SQ9FK: edytowalna nazwa stacji (topbar)
  static const char* antName(byte idx) { return antRAM[idx]; }
  static const char* siteName()        { return siteRAM; }
  static byte siteNameLen()            { return strlen(siteRAM); }

  static void loadAntNames() {
    strcpy_P(antRAM[0], (PGM_P)pgm_read_word(&antDefault[0]));  // OFF - staly (indeks 0, wybieralny zawsze)
#if defined(BCD_INPUT)
    strcpy_P(antRAM[7], (PGM_P)pgm_read_word(&antDefault[7]));  // sentinel trybu BCD (poz. 7)
#endif
    boolean ok = (EEPROM.read(0) == ANT_EE_MAGIC);
    for (byte k = 1; k <= 6; k++) {                            // SQ9FK: 6 anten (bylo 7)
      if (ok) {
        for (byte cc = 0; cc < ANT_MAXLEN; cc++)
          antRAM[k][cc] = EEPROM.read(1 + (k - 1) * ANT_MAXLEN + cc);
        antRAM[k][ANT_MAXLEN] = '\0';
      } else {
        strcpy_P(antRAM[k], (PGM_P)pgm_read_word(&antDefault[k]));
      }
    }
    if (EEPROM.read(SITE_MAG_OFF) == SITE_EE_MAGIC) {          // SQ9FK: nazwa stacji
      for (byte cc = 0; cc < ANT_MAXLEN; cc++)
        siteRAM[cc] = EEPROM.read(SITE_EE_OFF + cc);
      siteRAM[ANT_MAXLEN] = '\0';
    } else {
      strcpy_P(siteRAM, siteDefault);
    }
  }
  static void saveAntNames() {
    for (byte k = 1; k <= 6; k++)                             // SQ9FK: 6 anten
      for (byte cc = 0; cc < ANT_MAXLEN; cc++)
        EEPROM.update(1 + (k - 1) * ANT_MAXLEN + cc, antRAM[k][cc]);
    for (byte cc = 0; cc < ANT_MAXLEN; cc++)                  // SQ9FK: nazwa stacji
      EEPROM.update(SITE_EE_OFF + cc, siteRAM[cc]);
    EEPROM.update(0, ANT_EE_MAGIC);
    EEPROM.update(SITE_MAG_OFF, SITE_EE_MAGIC);
  }
  static byte hexNib(char h) {
    if (h >= '0' && h <= '9') return h - '0';
    if (h >= 'A' && h <= 'F') return h - 'A' + 10;
    if (h >= 'a' && h <= 'f') return h - 'a' + 10;
    return 0;
  }
  // Dekoduje wartosc z URL (po '=') do bufora dst, obcina do ANT_MAXLEN (#zabezpieczenie).
  static void parseName(const char* q, char* dst) {
    byte n = 0;
    while (*q && *q != ' ' && *q != '&' && n < ANT_MAXLEN) {
      char ch = *q++;
      if (ch == '+') ch = ' ';
      else if (ch == '%' && q[0] && q[1]) { ch = (hexNib(q[0]) << 4) | hexNib(q[1]); q += 2; }
      dst[n++] = ch;
    }
    dst[n] = '\0';
  }
#else
  static const __FlashStringHelper* antName(byte idx) {
    return (const __FlashStringHelper*)pgm_read_word(&antDefault[idx]);
  }
  static const __FlashStringHelper* siteName() {
    return (const __FlashStringHelper*)siteDefault;
  }
  static byte siteNameLen() { return strlen_P(siteDefault); }
#endif
#define Inputs      6      // number of antenna used ** not implemented ** //SQ9FK was 6
#define Ports       2      // number of - IN/OUT pair devices and LCD lines (support from 2 to 4)
#define LCDculumn  16      //
#define inputHigh          // enable input High level (default)
//#define serialECHO       // enable TX echo on serial port
//#define OTRSP            // enable serial OTSRP on serial port
// SQ9FK: OTRSP_TCP - surowe gniazdo TCP dla OTRSP, niezalezne od OTRSP (USB), moga byc wlaczone
// osobno albo razem. DOMYSLNIE WLACZONE razem z EthModule (WWW+OTRSP_TCP - np. do N1MM+ przez
// TCP) - zapas ZALEDWIE ~4 B, patrz docs/DESIGN.md. Port dowolny, nie narzucony przez protokol.
#define OTRSP_TCP
#define OTRSP_TCP_PORT 4534
//#define OTRSP_DEBUG
#define SERBAUD    9600    // [baud] Serial port baudrate
#define EthModule        // enable Ethernet module
// SQ9FK: DHCP usuniete z projektu - IP zawsze statyczne (patrz ip/gateway/subnet nizej, ustaw
// pod siec docelowa; edytowalne tez przez WWW+EEPROM przy WWW_EEPROM_NAMES). Powod: obsluga
// DHCP w oficjalnej bibliotece Arduino Ethernet kosztowala ~3,8 KB flash, a przydatna byla
// tylko w wariantach bez strony WWW - nie warto trzymac calej sciezki kodu dla tego przypadku.
//====================================================================
// SQ9FK: OTRSP (USB) i OTRSP_TCP sa NIEZALEZNE - kazdy moze byc wlaczony osobno (wspolny parser
// OTRSP_parse() kompiluje sie, gdy zdefiniowany jest ktorykolwiek z nich). DOMYSLNY BUILD to
// EthModule+OTRSP_TCP (strona WWW + OTRSP po TCP, np. dla N1MM+) - 97,0% flash, zapas ~910 B
// (patrz docs/DESIGN.md) - kazda zmiana w kodzie WWW/CSS/OTRSP_TCP MUSI byc zbudowana
// NAJPIERW na tym wariancie, bo najlatwiej go zepsuc. Samo OTRSP (USB) z EthModule tez sie
// miesci (95,4%, zapas ~1,4 KB). WSZYSTKIE TRZY naraz (EthModule+OTRSP+OTRSP_TCP) od 2026-07-29
// (po odzyskaniu ~660 B flash przy przegladzie bugow) TEZ sie miesci (97,3%, zapas ~824 B) -
// wczesniej byla tu blokada #error (brakowalo ~116 B przed tym przegladem), odblokowano.
// SQ9FK: sprzet sieciowy (W5500/DHCP) potrzebny zarowno dla strony WWW (EthModule) jak i dla
// surowego TCP OTRSP (OTRSP_TCP) - bring-up jest wspolny, tylko serwer/tresc na porcie sa inne.
#if defined(EthModule) || defined(OTRSP_TCP)
  // SQ9FK: oficjalna biblioteka Arduino (arduino-libraries/Ethernet) - Ethernet2/Ethernet3 sa
  // przestarzale/nieutrzymywane. Jeden naglowek <Ethernet.h> (EthernetClient/Server/Dhcp w srodku,
  // bez osobnych util.h/Dhcp.h/EthernetServer.h jak w Ethernet2). Auto-detekcja chipu W5100/
  // W5200/W5500, domyslny pin CS=10 dla AVR (zgodny z PCB: D10-D13 SPI -> W5500).
  #include <Ethernet.h>
  #include <SPI.h>
#endif
#include "Wire.h"
#include <LiquidCrystal.h>
LiquidCrystal lcd(A0, A1, 7, 6, 5, 4);     // rev. 0.3
#if defined(EthModule) || defined(OTRSP_TCP)
  // SQ9FK: mac/ip/gateway/subnet wspolne dla strony WWW (EthModule) i surowego TCP (OTRSP_TCP).
  // IP zawsze statyczne (bez DHCP) - dostosuj ip/gateway/subnet ponizej pod siec docelowa
  // (lub edytuj po flashowaniu przez WWW+EEPROM, patrz WWW_EEPROM_NAMES nizej).
  byte mac[] = {0xDE, 0xAD, 0xBE, 0xEF, 0xFE, 0xEE};
  IPAddress ip(10, 10, 10, 1);           // IP
  IPAddress gateway(0, 0, 0, 0);          // GATE (brak bramy - siec izolowana)
  IPAddress subnet(255, 255, 255, 0);     // MASK
  IPAddress myDns(8, 8, 8, 8);            // DNS (google pub)
#if defined(WWW_EEPROM_NAMES)
  // SQ9FK: konfiguracja sieciowa (IP/gateway/maska/DNS) edytowalna przez WWW (EthModule) + EEPROM,
  // zamiast na sztywno w kodzie. Ladowana tez dla OTRSP_TCP (bez formularza edycji), gdyby EEPROM
  // mial juz zapisane wartosci z wczesniejszego flashowania wariantu WWW na tym samym urzadzeniu.
  // Osobny magic (za sekcja nazwy stacji) - stary EEPROM bez tej sekcji zostawia domyslne IP.
  #define NET_EE_MAGIC 0x5C
  #define NET_MAG_OFF  (SITE_EE_OFF + ANT_MAXLEN)      // 79: bajt-magic sekcji sieciowej
  #define NET_EE_OFF   (NET_MAG_OFF + 1)                // 80: 4x4 B (ip/gateway/maska/dns)
  IPAddress* const netCfg[4] = {&ip, &gateway, &subnet, &myDns};
  const char netLbl0[] PROGMEM = "IP";
  const char netLbl1[] PROGMEM = "Gateway";
  const char netLbl2[] PROGMEM = "Maska";
  const char netLbl3[] PROGMEM = "DNS";
  const char* const netLbl[] PROGMEM = {netLbl0, netLbl1, netLbl2, netLbl3};
  const char netCode[] PROGMEM = "IGMD";       // pierwsza litera kodu pola: NI/NG/NM/ND

  static void loadNetConfig() {
    if (EEPROM.read(NET_MAG_OFF) == NET_EE_MAGIC)
      for (byte f = 0; f < 4; f++)
        for (byte i = 0; i < 4; i++)
          (*netCfg[f])[i] = EEPROM.read(NET_EE_OFF + f * 4 + i);
  }
  static void saveNetConfig() {
    for (byte f = 0; f < 4; f++)
      for (byte i = 0; i < 4; i++)
        EEPROM.update(NET_EE_OFF + f * 4 + i, (*netCfg[f])[i]);
    EEPROM.update(NET_MAG_OFF, NET_EE_MAGIC);
  }
  // SQ9FK: kopiuje wartosc z URL (do spacji/&/limitu) do bufora i probuje sparsowac jako adres
  // IP (IPAddress::fromString - a.b.c.d). Zwraca false bez modyfikacji `out` przy zlym wejsciu
  // (fromString moze czesciowo nadpisac bajty przy bledzie, wiec parsujemy do zmiennej tymczasowej
  // w miejscu wywolania, nie bezposrednio do zywej konfiguracji).
  static bool parseIPField(const char* q, IPAddress &out) {
    char buf[16];
    byte n = 0;
    while (*q && *q != ' ' && *q != '&' && n < sizeof(buf) - 1) buf[n++] = *q++;
    buf[n] = '\0';
    return out.fromString(buf);
  }
  // SQ9FK: ustawia jedno pole sieciowe (I/G/M/D, patrz netCode[]) - wspolne dla formularza WWW
  // i komend po Serial (patrz serialEvent/loop nizej), zeby nie duplikowac tej samej petli.
  static bool setNetField(char code, const char* val) {
    for (byte f = 0; f < 4; f++) {
      if (code == (char)pgm_read_byte(&netCode[f])) {
        IPAddress tmp;
        if (parseIPField(val, tmp)) { *netCfg[f] = tmp; saveNetConfig(); return true; }
        return false;
      }
    }
    return false;
  }
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
void loop() {
  wdt_reset();      // SQ9FK: watchdog - jesli petla sie zawiesi (WWW/TCP/USB/cokolwiek), reset po ~8 s
#if defined(EthModule)
  // SQ9FK: przycisk Restart w Settings - flaga ustawiona POPRZEDNIA iteracja (po wyslaniu
  // pelnej odpowiedzi klientowi), wiec restartujemy dopiero teraz. Skrocony timeout WDT zamiast
  // np. skoku na adres 0 - to jedyny NIEZAWODNY sposob softwarowego resetu na AVR (czysci tez
  // peryferia, nie tylko licznik rozkazow).
  if (pendingRestart) { wdt_enable(WDTO_15MS); while (1) {} }
#endif


    //=====[ OTRSP / edycja sieci po Serial ]=================
#if defined(OTRSP) || (defined(WWW_EEPROM_NAMES) && (defined(EthModule) || defined(OTRSP_TCP)))
  if (stringComplete) {
#if defined(WWW_EEPROM_NAMES) && (defined(EthModule) || defined(OTRSP_TCP))
    // SQ9FK: N{I|G|M|D}={a.b.c.d}\r - ten sam format co WWW (/?N{kod}={wartosc}), zeby dalo sie
    // poprawic zle skonfigurowana siec (np. zly gateway) bez dostepu do strony WWW.
    if (in_buf[0] == 'N' && memchr("IGMD", in_buf[1], 4) && in_buf[2] == '=') {
      Serial.println(setNetField(in_buf[1], in_buf + 3) ? F("OK") : F("ERR"));
    }
#if defined(OTRSP)
    else {
      OTRSP_parse(in_buf, Serial);   // kanal USB
    }
#endif
#else
#if defined(OTRSP)
    OTRSP_parse(in_buf, Serial);   // kanal USB
#endif
#endif
    stringComplete = false;
  }
#endif

  //=====[ GPIOs 4]=================
#if defined(BCD_INPUT)
  for (i = 0; i < Ports; i++) {
    if (menu1state == 1 && i == enc0Pos) {
      if (port[i][1] != 7) { //SQ9FK poz. 7 = tryb BCD (sentinel); inaczej tryb reczny
        port[i][4] = 1;
      } else {
        port[i][4] = 0;
      }
    } else if (port[i][4] == 0) {
      rx(port[i][0], i, 0, port[i][5]);   // auto: wybor anteny z BCD radia
    }
  }
#endif
  updateCollisions();
  //=====[ Ethernet ]=================
#if defined(EthModule)
  EthernetClient client = server.available();
  if (client) {
    // SQ9FK (#5): bufor linii zadania bez String (mniej sterty). Dla komend anteny
    // potrzebne indeksy 7 (bank) i 8-9 (kod); dla edycji nazw (WWW_EEPROM_NAMES) tez wartosc.
    // SQ9FK: 56 B - "GET /?N1=" (9) + nazwa 11 znakow w pelni %XX-zakodowana (33) + " HTTP/1.1\r\n"
    // (11) = 53 + NUL = 54, z niewielkim zapasem. Bylo 48 B - mocno zakodowana nazwa (dużo znakow
    // specjalnych) moglaby sie obcinac w polowie (bezpiecznie, ale dawalo znieksztalcona nazwe).
#if defined(WWW_EEPROM_NAMES)
    char reqBuf[56];
#else
    char reqBuf[16];
#endif
    byte reqLen = 0;
    // SQ9FK: timeout odczytu - bez tego wolny/zawieszony klient (albo taki co sie polaczy i nic
    // nie wysle) trzymalby te petle bez konca, blokujac cala reszte loop() (przelaczanie anten,
    // OTRSP) az do watchdoga (~8s reset calego urzadzenia zamiast zwyklego odrzucenia klienta).
    unsigned long reqStart = millis();
    // SQ9FK (#4): czytamy tylko pierwsza linie zadania (GET ...) i od razu odpowiadamy
    // -> mniej odczytow i krotsza blokada loop() (switching/PTT).
    while (client.connected() && millis() - reqStart < 2000) {
      int avail = client.available();
      if (avail > 0) {
        // SQ9FK: czytaj dostepne bajty jednym recv (zamiast po bajcie -> mniej transakcji SPI)
        int room = (int)sizeof(reqBuf) - 1 - reqLen;
        if (avail > room) avail = room;
        if (avail > 0) reqLen += client.read((uint8_t*)reqBuf + reqLen, avail);
        reqBuf[reqLen] = '\0';
        if (memchr(reqBuf, '\n', reqLen) || reqLen >= (int)sizeof(reqBuf) - 1) {
          // koniec linii zadania (lub pelny bufor) -> generuj odpowiedz
          BufP out(client);   // SQ9FK: cala strona przez bufor (mniej segmentow TCP = szybciej)
          // SQ9FK: /?J - maszynowy odczyt stanu dla rotator_wifi_bridge (most rotor<->antena).
          // Reuzywa HTTP_HEAD (juz istniejacy PROGMEM ze statusem+naglowkami) zamiast nowego
          // literalu - jedyny dodatkowy koszt to ten warunek + F("A=") + juz uzywane print()y.
          // Tresc po HTTP_HEAD zaczyna sie resztkami "<!DOCTYPE html>..." - nieistotne, bo
          // konsumentem jest parser na moscie (szuka podciagu "A=" i czyta liczby po nim), nie
          // przegladarka. Patrz docs/DESIGN.md. 3./4. pole (2026-08-03) to stan Radio Flex
          // (flexState[]). 5./6. pole (2026-08-04) to port[i][3] - flaga "ten TRX przegral
          // kolizje" z updateCollisions(), juz WYLICZONA i asymetryczna (tylko przegrywajacy ma
          // 1) - most pokazywal dotad OBA TRX na czerwono, bo sam liczyl symetryczny warunek
          // (ant1==ant2) z pol A=ant1,ant2 zamiast poznac PRAWDZIWEGO "przegranego" stad.
          if (reqBuf[6] == 'J') {
            out.print((const __FlashStringHelper*)HTTP_HEAD);
            out.print(F("A="));
            out.print(port[0][1]);
            out.print(',');
            out.print(port[1][1]);
            out.print(',');
            out.print(flexState[0]);
            out.print(',');
            out.print(flexState[1]);
            out.print(',');
            out.print(port[0][3]);
            out.print(',');
            out.print(port[1][3]);
            out.done();
            break;
          }
          // SQ9FK: /?K - nazwy anten 1..6 + nazwa stacji dla rotator_wifi_bridge (legenda pod
          // przyciskami + nagl. karty Anteny), zeby pokazywal PRAWDZIWE dane z tego urzadzenia
          // zamiast osobnej, recznie duplikowanej kopii. antName(k)/siteName() zwracaja char*
          // (WWW_EEPROM_NAMES) lub FSH* (PROGMEM) zaleznie od flagi - out.print() obsluguje oba,
          // jak wszedzie indziej w tym pliku. Separator ',' - zaden z tych stringow nie powinien
          // go zawierac (parseName() tego nie zabrania, ale nikt tak nie robi). Nazwa stacji jest
          // 7-mym polem (po 6 nazwach anten), a nie osobnym endpointem - +7 B, nie +68 B jak nowy
          // endpoint reuzywajacy HTTP_HEAD (patrz docs/DESIGN.md - budzet flash ~106 B).
          if (reqBuf[6] == 'K') {
            out.print((const __FlashStringHelper*)HTTP_HEAD);
            out.print(F("K="));
            for (byte k = 1; k <= 6; k++) {
              if (k > 1) out.print(',');
              out.print(antName(k));
            }
            out.print(',');
            out.print(siteName());
            out.done();
            break;
          }
          // ---- naglowek HTTP + <head> + CSS: statyczne, z PROGMEM (przez bufor) ----
          out.print((const __FlashStringHelper*)HTTP_HEAD);
          out.print(F("<title>"));
          out.print(Inputs);
          out.print(F("x"));
          out.print(Ports);
          out.print(F(" "));
          out.print(siteName());
          out.println(F(" - Antenna switch</title>"));
          // SQ9FK: dawny <meta refresh> przeladowywal strone co 10 s bezwarunkowo - zwijal
          // rozwiniete Settings (<details>) w trakcie edycji, zanim uzytkownik zdazyl zapisac.
          // Zastapione JS-em: odswieza po 10 s TYLKO gdy zaden <details> nie jest otwarty,
          // w przeciwnym razie odracza sprawdzenie o 2 s (petla, az uzytkownik zwinie Settings).
          out.print(F("<script>function r(){document.querySelector('[open]')?setTimeout(r,2000)"
                       ":location.href='http://"));
          out.print(Ethernet.localIP());
          out.println(F("'}setTimeout(r,10000)</script>"));
          out.print((const __FlashStringHelper*)HTTP_HEAD2);
          // SQ9FK: topbar - kropka statusu (czerwona gdy napiecie poza 10-15 V) + nazwa stacji
          float vv = volt(analogRead(A3));
          out.print(F("<nav class=\"tb\"><span class=\"dot"));
          if (vv < 10 || vv > 15) out.print(F(" bad"));
          out.print(F("\"></span>"));
          out.print(siteName());
          out.print(F(" "));
          out.print(Inputs);
          out.print(F("x"));
          out.print(Ports);
          out.println(F(" Antenna Switch</nav>"));
          out.println(F("<div class=\"wrap\">"));
          // SQ9FK (#5): parsuj prosto z bufora. Zadania:
          //   /?S{bank}{kod}   - wybor anteny / tryb (00..06, 20/21)
          //   /?N{k}={nazwa}   - edycja nazwy anteny 1..6           (WWW_EEPROM_NAMES)
          //   /?NS={nazwa}     - edycja nazwy stacji (topbar)        (WWW_EEPROM_NAMES)
          //   /?N{I|G|M|D}={a.b.c.d} - edycja IP/gateway/maski/DNS   (WWW_EEPROM_NAMES)
          //   /?F{s}{0|1}      - zalaczenie/wylaczenie Flex s=1/2 (GPA7/GPB7)
          // SQ9FK: kazde pole Settings ma WLASNY formularz/submit (parser czyta tylko JEDEN
          // parametr na zadanie, patrz reqBuf[6..]) - zapisanie IP/gateway/maski/DNS wymaga wiec
          // do 4 klikniec OK z rzedu. Zeby uzytkownik nie musial za kazdym razem ponownie
          // rozwijac karty, po zapisaniu KTOREGOKOLWIEK pola Settings odpowiedz renderuje
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

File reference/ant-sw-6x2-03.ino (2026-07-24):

//#include <Arduino.h>

/*

  6 x 2 Antenna control
  ----------------------
  http://remoteqth.com/6x2-antenna-controler.php
  2016-12 by OK1HRA
  rev 0.3

  ___               _        ___ _____ _  _
  | _ \___ _ __  ___| |_ ___ / _ \_   _| || |  __ ___ _ __
  |   / -_) '  \/ _ \  _/ -_) (_) || | | __ |_/ _/ _ \ '  \
  |_|_\___|_|_|_\___/\__\___|\__\_\|_| |_||_(_)__\___/_|_|_|


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
  Features:
  INPUTS
    - Four TRX
    - Automatic four bit BCD - may be activate LOW or HIGH, must be configure on pcb and firmware
    - Manual menu with light button and rotary encoder
    - Manually through the web interface
    - Free configure matrix input table
  OUTPUTS
    - 6 antennas
    - 2x6 gpio outputs (12V or GND output dependancy to use IO driver)
    - serialline
    - web page
  BLOCKED
    - more inpunts in same time = select only one antenna for each TRX
    - colision between TRX and same antenna
    - switching during PTT ON, separately for each TRX
    - interruption PTT path if colision detected
  SHOW on LCD/WEB
    - active number outputs
    - colision
    - PTT ON
    - name of the antenna
    - power voltage
  ETHERNET (with optional IP module)
    - DHCP
    - fixed IP
    - Show IP on LCD during start up
  - refresh input < 25 ms two TRX, < 55 ms four TRX (arduino Nano)
  - all mounted on compact pcb - useable without enclosure
  - output connector included power for switch - all in one cable
  - Ethernet hardware support
  - support two line LCD, one for each TRX
  - measure input voltage
  
  Changelog:
  2016-12 change to rev 0.3 pinout

Dhcp.h change from
  int beginWithDHCP(uint8_t *, unsigned long timeout = 60000, unsigned long responseTimeout = 5000);  
to
  int beginWithDHCP(uint8_t *, unsigned long timeout = 6000, unsigned long responseTimeout = 5000);  


  
*/
//=====[ Settings ]===================================================
char* ant[] = {
  "OFF",  // <-- do not change this line
  "160m INV-V",
  "80m Dipole",
  "Delta 80/40",
  "GXP11 40",
  "GXP11 20/10",
  "UB50",
  "6m 5el Yagi",
  "M-off->BCD",  // <-- do not change this line
};
#define Inputs      6      // number of antenna used ** not implemented ** //SQ9FK was 6
#define Ports       2      // number of - IN/OUT pair devices and LCD lines (support from 2 to 4)
#define LCDculumn  16      //
#define inputHigh          // enable input High level (default)
//#define serialECHO       // enable TX echo on serial port
#define OTRSP            // enable serial OTSRP on serial port
#define OTRSP_DEBUG
#define SERBAUD    9600    // [baud] Serial port baudrate
//#define EthModule        // enable Ethernet module
//#define __USE_DHCP__       // Uncoment to Enable DHCP
//====================================================================
#if defined(EthModule)
  #include <util.h>
  #include <Ethernet2.h>
  #include <Dhcp.h>
  #include <EthernetServer.h>
  #include <SPI.h>
#endif
#include "Wire.h"
#include <LiquidCrystal.h>
LiquidCrystal lcd(A0, A1, 7, 6, 5, 4);     // rev. 0.3
#if defined(EthModule)
  byte mac[] = {0xDE, 0xAD, 0xBE, 0xEF, 0xFE, 0xEE};
  IPAddress ip(192, 168, 5, 45);         // IP
  IPAddress gateway(192, 168, 5, 254);    // GATE
  IPAddress subnet(255, 255, 255, 0);     // MASK
  IPAddress myDns(8, 8, 8, 8);            // DNS (google pub)
  EthernetServer server(80);              // server PORT
  String HTTP_req;
#endif
int BCDmatrixOUT[2][16] = {
                     { 0,  1,  2,  3,  4,  5,  4,  5,  4,  5,  6,  3,  3,  3,  3,  3 },
                     { 0,  1,  2,  3,  4,  5,  4,  5,  4,  5,  6,  3,  3,  3,  3,  3 },
};
byte a = 0;
byte b = 0;
unsigned int ab;
//long Loops=0;
int i = 0;
int j = 0;
int c = 0;
int val;
int e = 0;
const int enc0PinA = 2;
const int enc0PinB = 3;
const int sw = 9;
const int swLED = 8;
int enc0Pos = 0;
byte enc0PinALast = HIGH;
int n = HIGH;
boolean menu1state = false;
boolean menu2state = false;
long Timeout[5][2] = {
  {0, 100},
  {0, 500},
  {0, 1000},
  {0, 5000},
  {0, 3000},
};
boolean buttonActive = false;
boolean longPressActive = false;
byte ERR[8] = {0b11111, 0b11011, 0b11011, 0b11011, 0b11011, 0b11111, 0b11011, 0b11111};
byte PTT[8] = {0b11111, 0b10011, 0b10101, 0b10101, 0b10011, 0b10111, 0b10111, 0b11111};
byte MAN[8] = {0b11111, 0b01110, 0b00100, 0b01010, 0b01110, 0b01110, 0b01110, 0b11111};
byte Cursor[8] = {0b00000, 0b00000, 0b11000, 0b11000, 0b11000, 0b00000, 0b00000, 0b00000};
byte mCursor[8] = {0b00011, 0b00010, 0b11010, 0b11010, 0b11010, 0b00010, 0b00011, 0b00000};
byte m[8] = {0b00011, 0b00010, 0b00010, 0b00010, 0b00010, 0b00010, 0b00011, 0b00000};
String Note;
int port[8][6] = {
  //  adr   # ptt Err Manual part
  { 0x21, 0, 0,  0, 0, 1 }, // port1 IN
  { 0x21, 0, 0,  0, 0, 2 }, // port2 IN
  { 0x23, 0, 0,  0, 0, 1 }, // port3 IN
  { 0x23, 0, 0,  0, 0, 2 }, // port4 IN
  { 0x20, 0, 0,  0, 0, 1 }, // port1 OUT
  { 0x20, 0, 0,  0, 0, 2 }, // port2 OUT
  { 0x22, 0, 0,  0, 0, 1 }, // port3 OUT
  { 0x22, 0, 0,  0, 0, 2 }, // port4 OUT
};

#if defined(OTRSP)
char        in_buf[200];  // UART input buffer
static byte in_len;      // Number of chars in buffer
boolean stringComplete = false;  // whether the string is complete
#define COMPARE(command)  (memcmp_P(in_buf, PSTR(command), \
                                    sizeof(command)-1) == 0)

#define QCOMPARE(command) (memcmp_P(in_buf+1, PSTR(command), \
                                    sizeof(command)-1) == 0)

#define AFTER(command) (sizeof(command)-1)
#endif
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

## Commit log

2026-07-24 Initial commit: SP9PDF RemoteQTH 6x2 antenna switch firmware
    SQ9FK modifications of OK1HRA remoteQTH 6x2 controller (rev 0.3):
    7th antenna position, OTRSP/SO2R control, GXP11 collision blocking,
    disabled PTT check, voltage warnings. Includes reference variants
    (orig/03/04), README, .gitignore and GPLv3 LICENSE.
    [ant-sw-6x2-03.ino, ant-sw-6x2-03_orig.ino, ant-sw-6x2-04.ino]
2026-07-24 Struktura PlatformIO, schemat/KiCad i analiza połączeń
    - platformio.ini (Nano ATmega328P, env stary/nowy bootloader)
    - src/main.ino (firmware) + reference/ (warianty historyczne)
    - docs/: schemat SVG + CONNECTIONS.md (pinout MCU, I2C, przekazniki,
    BCD/PTT, OTRSP) zweryfikowane netlista KiCad
    - hw/: projekt KiCad rev 03 (OK1HRA, CC BY-SA 4.0)
    - CLAUDE.md, README i LICENSE zaktualizowane
    [ant-sw-control.kicad_pcb, ant-sw-control.sch]
2026-07-24 Popraw lib_deps: LiquidCrystal wymagany w PlatformIO
    W PlatformIO LiquidCrystal nie jest w rdzeniu AVR (inaczej niz w Arduino IDE) -
    dodano arduino-libraries/LiquidCrystal do lib_deps. Build zweryfikowany:
    pio run -e nanoatmega328 => SUCCESS (Flash 44.4%, RAM 59%).
    Zaktualizowano README i CLAUDE.
2026-07-24 Usun ostrzezenia kompilatora (czysty build)
    - ant[] -> const char* (ISO C++ write-strings)
    - Timeout[][] -> unsigned long (sign-compare z millis())
    - Wire.requestFrom(addr, (byte)1) (rozwianie ambiguous overload)
    pio run -e nanoatmega328 => SUCCESS, 0 ostrzezen (Flash 44.4%, RAM 59%).
2026-07-24 Optymalizacja rozmiaru: -1808 B Flash, -264 B RAM
    Flash 93.2%->87.3% (26816 B), RAM 52.6%->39.7% (814 B). Build SUCCESS, 0 ostrzezen.
    - WWW: generowanie przyciskow poz. 0-7 zwiniete w petle, switch(GET) -> if
    (wygenerowany HTML bajt-w-bajt identyczny) -> glowny zysk Flash
    - port[8][6] int->byte (-48 B RAM)
    - BCDmatrixOUT int -> const byte PROGMEM (pgm_read_byte) (-64 B RAM)
    - ant[] -> PROGMEM + antName() (__FlashStringHelper) (-~88 B RAM)
    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
2026-07-24 Zabezpiecz HTTP_req przed niekontrolowanym wzrostem RAM (ETH)
    Bufor zadania HTTP byl rozszerzany o kazdy znak bez limitu -> przy dlugim
    lub zlosliwym zadaniu grozilo wyczerpanie RAM na Nano (2 KB).
    - reset bufora na poczatku kazdego zadania
    - twardy limit dlugosci 40 znakow (parsowanie uzywa tylko substring 7..10)
    - Build SUCCESS: Flash 87.4% (26842 B), RAM 39.7% (814 B), 0 ostrzezen
    [main.ino]
2026-07-24 Optymalizacja serwera WWW (1-4) z zachowaniem funkcjonalnosci
    Wygenerowany HTML bez zmian. Build SUCCESS: Flash 86.8% (26662 B), RAM 39.7% (814 B).
    1. Statyczny naglowek+CSS przeniesiony do PROGMEM (HTTP_HEAD/HTTP_HEAD2) i wysylany
    sendP() porcjami 64 B (client.write) zamiast ~30 print(F()) -> mniej zapisow do
    W5500 i krotsza blokada loop() (PTT/przelaczanie).
    2. Walidacja zadania: kontrola zakresu bankIdx (0..Ports-1). Obce zadania
    (/favicon.ico, gole GET /) nie przelaczaja anten i nie pisza poza port[] (fix OOB).
    3. Usuniety debugowy Serial.print(HTTP_req) z kazdego zadania.
    4. Serwer czyta tylko pierwsza linie zadania i od razu odpowiada (if c=='\n'),
    usunieta logika currentL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
    [main.ino]
2026-07-26 Projekt 6-antenowy + Radio Flex na GPA7/GPB7
    - Powrot do 6 anten (one-hot bit0..bit5): usunieta 7. antena oraz
    sprzezenie GXP11 poz. 4/5 wraz z blokada kolizji 4<->5 (poz. 4/5 sa
    teraz niezaleznymi antenami; ogolne wykrywanie kolizji zostaje).
    - bit7 (GPA7/GPB7) przestal sterowac antena - teraz dwa niezalezne
    wyjscia Radio Flex (flexState[2] -> Q1/K1/J7 i Q2/K2/J6), przelaczane
    osobnymi przyciskami WWW (/?F{s}{0|1}), kazde z konfigurowalna nazwa
    (/?NF{s}=..., flexRAM w EEPROM).
    - EEPROM: osobny bajt-magic 0x5A dla sekcji Flex (offset 67) - wgranie
    na istniejacy EEPROM zachowuje nazwy anten 1-6, nazwy Flex startuja
    z domyslnych.
    - Enkoder 0..6, przyciski/nazwy WWW 1-6, walidacja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
    [main.ino]
2026-07-26 Przeprojektowanie WWW: karty, statusy sekcji, ikony Flex, nazwa stacji
    Wyglad wg konwencji projektu rotator_wifi_bridge (ciemny teal, karty,
    akcent zolty, font Inter bez zewnetrznego linku):
    - Topbar: kropka napiecia + edytowalna NAZWA STACJI (EEPROM, komenda
    /?NS=, magic 0x5B @67 - nazwy anten 1-6 zachowane przy wgraniu na
    istniejacy EEPROM).
    - Karta "Anteny": naglowek ze statusami sekcji (chipy 50/50: numer +
    nazwa wlaczonej anteny) + wiersze TRX z przyciskami 1-6 i IKONA POWER
    Radio Flex (POWER_SVG, /?F{s}{0|1}).
    - Karta "Opis anten": legenda numer -> nazwa.
    - Karta "Settings" (<details>, zwinieta): nazwa stacji + nazwy anten
    1-6 + ukryty odczyt napiecia zasilania.
    - Usuniete: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
    [main.ino]
2026-07-26 Przyspieszenie serwera WWW: buforowanie wyjscia + batchowany odczyt
    W Ethernet2 kazde write() to osobny segment TCP z busy-waitem na
    SEND_OK, a client.print(F(...)) leci ZNAK PO ZNAKU -> setki drobnych
    pakietow na strone (bardzo wolno).
    - Klasa BufP (Print, bufor 128 B w RAM): cala strona idzie przez
    `BufP out(client)` (out.print/out.println, na koncu out.done()).
    Static (HTTP_HEAD/HEAD2/POWER_SVG) tez przez ten bufor. Efekt:
    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
2026-07-26 Odporny start DHCP + nieblokujace ostrzezenia napiecia; porzadki w delay
    Analiza i poprawa delayow w programie:
    - DHCP: Ethernet.begin(mac) uzywa domyslnego 60s timeoutu biblioteki
    (NIE 6s z komentarza - Dhcp.h niezmieniony). Dodane ponawianie
    (while begin(mac)==0, kazda proba do 60s) + fallback na static IP
    po 3 nieudanych probach (urzadzenie zawsze osiagalne) + info na LCD.
    - Ethernet.maintain() w loop() - odnawianie dzierzawy DHCP (bez tego
    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
2026-07-26 Jawny #include <Arduino.h> - naprawia falszywy blad PROGMEM w IntelliSense
    VS Code (rozszerzenie C/C++) parsuje surowy plik .ino bez doklejania
    Arduino.h, wiec nie zna makra PROGMEM (z <avr/pgmspace.h>) i podkreslal
    je jako blad. Kompilacja (pio/avr-gcc) automatycznie docieka Arduino.h
    przy .ino, wiec build byl OK.
    Odkomentowany jawny #include <Arduino.h> na gorze - dla kompilatora
    no-op (include-guardy), a IntelliSense przestaje zglaszac falszywy blad.
    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
2026-07-29 OTRSP: poprawki zgodnosci z protokolem (terminator, bufor, format AUX)
    Przeglad parsera wobec specyfikacji OTRSP (k1xm.org/OTRSP/OTRSP_Protocol.pdf)
    ujawnil trzy realne problemy:
    - KRYTYCZNY: serialEvent() konczyl komende na LF ('\n'), a protokol wymaga
    CR (\r, znak 13). Zgodny klient (np. N1MM+) wysyla \r, wiec parser nigdy
    nie widzial konca komendy - OTRSP z prawdziwym loggerem by nie dzialal.
    Terminator zmieniony na \r; samotny \n jest ignorowany (obsluga CRLF).
    - WYSOKI: brak kontroli granic przy zapisie do in_buf[64] - w polaczeniu
    z powyzszym (nigdy brak terminatora) gwarantowalo przepelnienie bufora
    i nadpisanie sasiednich zmiennych globalnych. Dodana kontrola in_len.
    - SRE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
    [main.ino]
2026-07-29 WWW: responsywnosc mobile (safe-area-inset, wieksze cele dotykowe, theme-color)
    Dodany @media (max-width:520px) w CSS strony (mirror w main.ino i
    tools/websim.html): kompaktowy topbar z uwzglednieniem notcha
    (env(safe-area-inset-*)), wieksze przyciski/cele dotykowe (min. 2.75rem)
    dla anten/Flex na waskich ekranach, dopasowanie chipow statusu i wiersza
    TRX. Dodany <meta name="theme-color"> oraz padding-bottom z
    safe-area-inset-bottom (pasek nawigacji na telefonach z gestami).
    Build (pio run -e nanoatmega328): SUCCESS, Flash 99,7% / RAM 45,6%.
    Flash bardzo ciasny (~94 B wolne) - kolejne dodatki do WWW wymagaja
    odchudzenia CSS/markup.
    [main.ino]
2026-07-29 Dodaj OTRSP_TCP: OTRSP rownolegle po USB i surowym TCP
    Nowa opcja #define OTRSP_TCP (wymaga OTRSP, wyklucza sie z EthModule -
    #error w compile-time pilnuje obu regul). Pozwala sterowac przelacznikiem
    przez OTRSP jednoczesnie po USB i po surowym gniezdzie TCP, bez strony
    WWW (ta i Ethernet+OTRSP_TCP nie miesca sie razem w flash ATmega328).
    Pomiar (usuniecie ciala strony WWW, zastapione zaslepka accept+close):
    sama strona WWW kosztuje ~8 KB flash (HTML/CSS/BufP/print-y) - NIE sam
    Ethernet2+DHCP (bazowo ~72,5%). Dzieki temu wariant OTRSP+OTRSP_TCP ma
    ~7,5 KB zapasu mimo Ethernetu/DHCP.
    Architektura:
    - OTRSP_parse(char *cmd, Print &out) - sparametryzowany zamiast
    twardego Serial. Serial i Et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
    [main.ino]
2026-07-29 Migracja Ethernet2 -> oficjalna arduino-libraries/Ethernet
    adafruit/Ethernet2 jest przestarzala/nieutrzymywana. Zastapiona oficjalna
    biblioteka Arduino (arduino-libraries/Ethernet @ ^2.0.2, platformio.ini).
    Zweryfikowane API: EthernetClient/EthernetServer/.maintain()/.available()
    identyczne dla naszego uzycia, auto-detekcja chipu W5100/W5200/W5500,
    domyslny CS pin=10 na AVR zgodny z PCB (D10-D13 SPI -> W5500). Includy
    uproszczone do <Ethernet.h> (bylo osobno util.h/Ethernet2.h/Dhcp.h/
    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
2026-07-29 Konfiguracja sieciowa (IP/gateway/maska/DNS) edytowalna przez WWW
    Zweryfikowano wyswietlanie IP na LCD po starcie - juz dzialalo poprawnie
    (lcd.print(Ethernet.localIP()), 5s), bez zmian.
    IP/gateway/maska/DNS przeniesione z hardkodowanych stalych do EEPROM,
    edytowalne w karcie Settings (4 pola w petli - oszczednosc flash, jak
    przyciski anten), komendy /?N{I|G|M|D}=a.b.c.d. Uzyto wbudowanego
    IPAddress::fromString() (nie wlasny parser) i IPAddress::printTo()
    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
2026-07-29 Usun zbedny Serial.print IP przy starcie
    LCD tuz ponizej i tak pokazuje adres IP (5s) - Serial.print("server is
    at ")/println(Ethernet.localIP()) bylo zbednym duplikatem. Dodatkowo
    przy OTRSP_TCP taki tekst na starcie zaśmiecal kanal serial uzywany
    przez protokol OTRSP tuz przed rozpoczeciem sesji.
    Build: default WWW SUCCESS 97,1% (29826B, +4B - artefakt kodowania
    skokow AVR-GCC, nie regresja); OTRSP+OTRSP_TCP SUCCESS 82,8% (-90B);
    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
2026-07-29 WWW: napraw responsywnosc mobile (wyrownanie siatki, centrowanie ikony Flex)
    - usun zdublowany margin na przyciskach (gap w kontenerze flex juz to robi) -
    power nie wskakuje juz samotnie na nowa linie na waskich ekranach
    - .flx: dodaj justify-content:center - ikona wysrodkowana w kwadracie dotykowym
    - .bcd/.bcdr: flex-basis:100% ponizej 520px - etykieta TRX na wlasnym wierszu,
    siatka przyciskow zawsze wyrownana do lewej niezaleznie od liczby zawiniec
    - websim.html: usun rozjazd .flx (resztki z epoki tekstowych przyciskow Flex),
    teraz bajt-w-bajt zgodny z CSS z main.ino
    Koszt: +10 B flash (29794/30720, 97,0%).
    README: zaktualizuj nieaktualne liczby flash/RAM dla wszystkich 3 wariantow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
    [main.ino]
2026-07-29 Dodaj watchdog + przycisk Restart, odzyskaj flash usuwajac duplikaty HTML
    Nowe funkcje bezpieczenstwa:
    - Watchdog (<avr/wdt.h>, zawsze wlaczony) - jesli loop() sie zawiesi (WWW,
    TCP OTRSP, USB OTRSP, cokolwiek), urzadzenie resetuje sie samo po ~8 s.
    wdt_enable(WDTO_8S) wlaczany DOPIERO na koncu setup() (po ~10 s delay()
    przy starcie - splash/napiecie/IP), inaczej wpadloby w petle resetow.
    MCUSR=0;wdt_disable() na poczatku setup() jako zabezpieczenie przed
    bootloaderami, ktore zostawiaja WDT wlaczony po poprzednim resecie.
    - Przycisk "Restart" w WWW Settings (/?R1) - realny, programowy restart
    zamiast samej informacji ze trzeba recznie zrestartowac urzadzenie.
    Watchdog ze skroco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
    [main.ino]
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2026-08-01 Napraw 6 bugow znalezionych w przegladzie firmware (2026-07-29)
    - OTRSP AUX1n/AUX2n: dodano walidacje zakresu anteny przed zapisem do
    port[idx][1] (byl OOB-read w antName(), osiagalny przez siec/USB)
    - WWW: dodano timeout 2000 ms na odczyt zadania klienta (brak go mogl
    zawiesic loop() w nieskonczonosc)
    - e/enc0Pos/Timeout[5][2]: dodano volatile (czytane w loop(), pisane w
    ISR enkodera encI())
    - show(): zastapiono globalny String Note stalobuforowym char noteBuf[]
    na stosie - unika fragmentacji sterty; efekt uboczny: odzyskano ~660 B
    flash
    - enc2(): naprawiono uzycie globalnego e zamiast przekazanego parametru
    count
    - reqBuf dla WWW_EEPROM_NAMES zwiekszony z 48 na 56 B (za malo na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
    [main.ino]
2026-08-01 Odblokuj 6. wariant: EthModule+OTRSP+OTRSP_TCP naraz
    Usunieto #error blokujacy jednoczesne wlaczenie strony WWW i obu
    kanalow OTRSP (USB + TCP) naraz. Od przegladu bugow 2026-07-29
    (odzyskanie ~660 B flash po usunieciu String z show()) ta kombinacja
    faktycznie sie miesci: Flash 97,3% (29896 B), RAM 55,0% (1127 B),
    zapas ~824 B - zmierzone i zweryfikowane buildem.
    To teraz najciasniejszy z szesciu dostepnych wariantow. Zaktualizowano
    README/CLAUDE.md/docs/DESIGN.md - wszystkie odniesienia do "pieciu
    wariantow" i zablokowanej kombinacji zastapiono aktualnym stanem.
    [main.ino]
2026-08-03 /?J: dodaj stan Radio Flex dla rotator_wifi_bridge (przycisk PWR)
    rotator_wifi_bridge dostal wlasny przycisk PWR per TRX, ale /?J zwracal
    dotad tylko wybrana antene - most nie mial jak poznac PRAWDZIWEGO stanu
    flexState[], tylko to co sam ostatnio wyslal (po restarcie mostu przycisk
    pokazywalby zawsze "off" niezaleznie od faktycznego stanu przekaznika).
    Dwa dodatkowe pola dopisane do istniejacej odpowiedzi (ten sam trik co
    nazwa stacji w /?K - dopisanie do juz istniejacego printa, nie nowy
    endpoint): A={ant1},{ant2},{flex1},{flex2}. Zmierzone na obu najciasniejszych
    wariantach przed commitem: domyslny EthModule+OTRSP_TCP +36 B (zapas ~602 B),
    najciasniejszy EthModule+OTRSP+OTRSP_TCP +36 B (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
    [main.ino]
2026-08-03 WWW mobile: wyrownaj siatke przyciskow anten, 4+4 zamiast 5+3
    Trzy powiazane poprawki CSS dla widoku <=520px (telefony):
    1. .flx mialo margin-left:auto (wyrownanie do prawej krawedzi) -
    gdy power ladowal sam z "6" w krotkim, zawinietym wierszu, auto-
    margines wypychal go na sam kraniec, zostawiajac wielka dziure.
    Usuniete w media query (desktop bez zmian - power nadal przy
    prawej krawedzi, gdy wszystko miesci sie w jednym wierszu).
    2. Dodano niewidoczny element .brk (display:none domyslnie),
    wstawiany w HTML tuz przed antena "4". Na mobile staje sie flex-
    itemem o flex-basis:100%, wymuszajac zawiniecie dokladnie przed
    "4" - uklad 4+4 (-,1,2,3 / 4,5,6,power) zamiast nie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
    [main.ino]
2026-08-03 Napraw stary kolor kolizji na WWW zaraz po przelaczeniu anteny
    Wykrywanie kolizji (krok GPIO w loop()) wykonywalo sie PRZED obsluga
    zadania WWW w tej samej iteracji, wiec renderowana odpowiedz pokazywala
    flage kolizji sprzed dopiero co wykonanej zmiany (port[bankIdx][1] =
    getVal). Bug wystepowal losowo (dowolne urzadzenie/przegladarka, nie
    tylko mobile), w zaleznosci od tego, czy poprzedni stan kolizji roznil
    sie od nowego - poprawny kolor pojawial sie dopiero po recznym
    odswiezeniu (kolejna iteracja loop() juz liczyla na biezaco).
    Logika liczenia kolizji (port[i][3]) i wyjsc (port[i+4][1]) wydzielona
    do wspolnej funkcji updateCollisions() - wolana jak dotychczas w kroku
    GPIO co iteracje, O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
    [main.ino]
2026-08-03 Napraw 5 bugow w wykrywaniu kolizji + dodaj brakujaca dokumentacje
    Wykryte i naprawione (patrz updateCollisions() w main.ino):
    1. Stary kolor kolizji na WWW zaraz po przelaczeniu anteny - krok GPIO
    liczyl kolizje PRZED obsluga zadania WWW w tej samej iteracji
    loop(), trzeba bylo recznie odswiezac strone.
    2. Falszywa kolizja przy OFF+OFF - brak warunku != 0 w porownaniu
    port[i][1]==port[j+4][1].
    3. Atrybucja: kolor czerwony (i "OFF" zamiast nazwy anteny) na gornym
    chipie statusu dostaje teraz TYLKO TRX, ktory faktycznie przelaczyl
    sie na zajeta antene - ten, kto juz tam byl, zostaje bez zmian,
    niezaleznie od numeru TRX.
    4. Gorny chip statusu ignorowal port[i][3] - pokazywal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
    [main.ino]
2026-08-04 /?J: dodaj flage kolizji per TRX dla rotator_wifi_bridge
    Most liczyl kolizje sam, symetrycznie z samych numerow anten - pokazywal
    oba TRX na czerwono zamiast tylko tego, ktory faktycznie przegral.
    updateCollisions() juz liczy to poprawnie i asymetrycznie w port[i][3],
    tylko nie bylo to nigdzie wysylane. Dwa kolejne pola w A=... (ten sam
    trik co przy Radio Flex): A=ant1,ant2,flex1,flex2,col1,col2.
    Zmierzone na obu pilnowanych wariantach: +36 B na kazdym.
    Domyslny (EthModule+OTRSP_TCP): 98,8% (30358 B), zapas ~362 B.
    Najciasniejszy (EthModule+OTRSP+OTRSP_TCP): 99,0% (30410 B), zapas ~310 B.
    tools/serve.py zaktualizowany o te sama logike atrybucji (ktory TRX wlasnie
    przelaczyl sie na zajeta a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
    [main.ino]

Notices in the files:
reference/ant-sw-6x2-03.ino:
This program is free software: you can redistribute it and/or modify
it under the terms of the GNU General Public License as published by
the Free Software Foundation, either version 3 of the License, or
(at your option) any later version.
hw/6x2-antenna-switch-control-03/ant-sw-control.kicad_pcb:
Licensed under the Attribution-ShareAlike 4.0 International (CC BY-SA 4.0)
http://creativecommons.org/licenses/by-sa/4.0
